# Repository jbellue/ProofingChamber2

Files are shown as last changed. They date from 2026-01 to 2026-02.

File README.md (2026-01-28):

# Proofing Chamber 2

A smart, temperature-controlled proofing chamber project.

## Repository Structure

- firmware/ — ESP32 firmware (PlatformIO)
- hardware/ — KiCad designs and vendor references
  - boards/ — device PCB projects
  - libraries/ — project symbols/footprints
  - docs/ — exports (PDFs, BOMs)
  - third_party/ — external references (git submodules)

## Quick Start

### Firmware

1. Install PlatformIO (VS Code extension or CLI)
2. Build from the firmware folder:

```
cd firmware
pio run
```

### Hardware Vendor References

If the repository was cloned without submodules, fetch them:

```
git submodule update --init --recursive
```

## Detailed Docs

- See firmware details in firmware/README.md
- Hardware-specific docs live under hardware/ (or board project folders)

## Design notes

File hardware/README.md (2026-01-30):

OLED symbol and footprint: https://www.snapeda.com/parts/OLED%20128x64%201.3%22%20I2C/UNIVERSAL-SOLDER%20Electronics%20Ltd/view-part/
OLED 3d model: https://grabcad.com/library/1-3-oled-display-128x64-1

Encoder 3d model: https://www.snapeda.com/parts/PEC11R-4020F-S0024/Bourns/view-part/

ESP32-C3: https://www.snapeda.com/parts/ESP32-C3%20SuperMini_TH/Espressif%20Systems/view-part/

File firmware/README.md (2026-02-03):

# Proofing Chamber

A smart temperature-controlled proofing chamber controller, built with ESP32-C3 and a 128x64 OLED display, with both physical controls and a web interface.

## Interfaces

### Physical Interface
- **Display**: SH1106 128x64 OLED (I2C interface)
- **Input**: Rotary encoder with push-button switch for menu navigation
- **LEDs**: Visual indicators for heating (GPIO 6) and cooling (GPIO 5) modes

### Web Interface
- **Access**: Browser-based control panel accessible on local network
- **Features**: Live temperature monitoring, mode control, settings adjustment
- **Documentation**: See [WEB_INTERFACE.md](WEB_INTERFACE.md)

Both interfaces work concurrently and share the same device state.

## Hardware

### Components

- **Microcontroller**: ESP32-C3-DevKitM-1
- **Display**: SH1106 128x64 OLED (I2C interface)
- **Temperature Sensor**: DS18B20 (1-Wire protocol)
- **Rotary Encoder**: With push-button switch for menu navigation
- **Relays**: 
  - Heating relay (GPIO 2)
  - Cooling relay (GPIO 1)
- **LEDs**:
  - Proofing LED (GPIO 6) - indicates heating mode
  - Cooling LED (GPIO 5) - indicates cooling mode

### Wiring Diagram

```
ESP32-C3
├── GPIO 0  → DS18B20 (1-Wire)
├── GPIO 1  → Cooling Relay
├── GPIO 2  → Heating Relay
├── GPIO 3  → Rotary Encoder CLK
├── GPIO 4  → Rotary Encoder DT
├── GPIO 5  → Cooling LED (cathode to GND)
├── GPIO 6  → Proofing LED (cathode to GND)
├── GPIO 10 → Rotary Encoder SW
├── SDA (GPIO 8)  → SH1106 OLED SDA
├── SCL (GPIO 9)  → SH1106 OLED SCL
└── GND → All grounds connected

Power:
├── 5V → OLED VCC, Relay logic power
├── 3.3V → ESP32 power
└── GND → All grounds
```

## Features

### Temperature Control

- **Heating Mode**: Maintains target temperature using hysteresis control
  - Turns heater ON below lower limit
  - Turns heater OFF above upper limit
- **Cooling Mode**: Maintains target temperature with active cooling
  - Turns cooler ON above upper limit
  - Turns cooler OFF below lower limit

### Menu System

Navigate with rotary encoder, select with push button:

1. **Mettre en pousse** (Start Proofing) - Immediate heating mode
2. **Mettre en froid** (Cooling)
   - Pousser à... (Proof at specific time)
   - Pousser dans... (Proof in X time)
3. **Réglages** (Settings)
   - **Chaud** (Heating Settings)
     - Lower temperature limit
     - Upper temperature limit
   - **Froid** (Cooling Settings)
     - Lower temperature limit
     - Upper temperature limit
   - **Avancés** (Advanced Settings)
     - Données (Display current temperature)
     - Reset du WiFi (Reset WiFi & reboot)
     - Fuseau horaire (Timezone)
     - Redémarrer (Reboot)

### Data Storage

Settings are persisted to ESP32 NVS (Non-Volatile Storage) using the Preferences library:

```
Preference Keys:
  - h_lower
  - h_upper
  - c_lower
  - c_upper
  - timezone
```

Default values:
- **Heating**: Range 28-35°C
- **Cooling**: Range 2-7°C

### Network Features

- WiFi Manager for easy WiFi configuration
- NTP time synchronization (configurable timezone)
- WiFi reset option available in advanced settings
- **Web Interface**: Browser-based control panel on port 80
  - Real-time temperature monitoring
  - Remote mode switching (heating/cooling/off)
  - Temperature settings adjustment
  - Works concurrently with physical interface
  - See [WEB_INTERFACE.md](WEB_INTERFACE.md) for details

## Installation & Setup

### Prerequisites

- PlatformIO IDE or VS Code with PlatformIO extension
- Python 3.6+

### First Boot

1. Device will attempt to connect to WiFi via WiFi Manager
2. If no WiFi found, connect to the ESP32's AP and configure WiFi
3. Device will sync time from NTP server
4. Main menu will appear on display

## Usage Guide

### Starting a Proof

1. From main menu, select **Mettre en pousse**
   - Immediately activates heating mode
   - Displays elapsed time and current temperature
   - Shows temperature graph
   - Press button to cancel and return to menu

### Cooling with Delayed Start

1. From main menu, select **Mettre en froid** → **Pousser dans...**
2. Use encoder to set hours and minutes for delay
3. Press button to confirm each field
4. Device will cool until specified time, then switch to heating
5. Proofing screen appears when time reached

### Scheduled Proof

1. From main menu, select **Mettre en froid** → **Pousser à...**
2. Set the time when proofing should start (current time shown by default)
3. Device will cool until that time, then switch to heating

### Adjusting Temperature Limits

1. Navigate to **Réglages** → **Chaud** or **Froid**
2. Select the limit you want to adjust
3. Use encoder to increase/decrease value
4. Press button to confirm and save

### Temperature Graph

- Displays on proofing and cooling screens
- X-axis: Time (most recent on right)
- Y-axis: Temperature scale (configured per mode)
- Updates every 10 seconds

## Development

### Architecture

The project uses a layered architecture:

```
UI Layer (Views)
    ↓
Controllers (Screen Logic)
    ↓
Services (Temperature, Storage, Network, Reboot)
    ↓
Hardware Drivers (InputManager, DisplayManager, DS18B20Manager)
    ↓
Hardware (ESP32 Peripherals)
```

### Key Classes

- `Menu` - Main menu navigation
- `ProofingController` - Heating mode logic
- `CoolingController` - Cooling mode logic
- `TemperatureController` - Relay control & hysteresis
- `StorageAdapter` - Persistent settings
- `NetworkService` - WiFi & NTP

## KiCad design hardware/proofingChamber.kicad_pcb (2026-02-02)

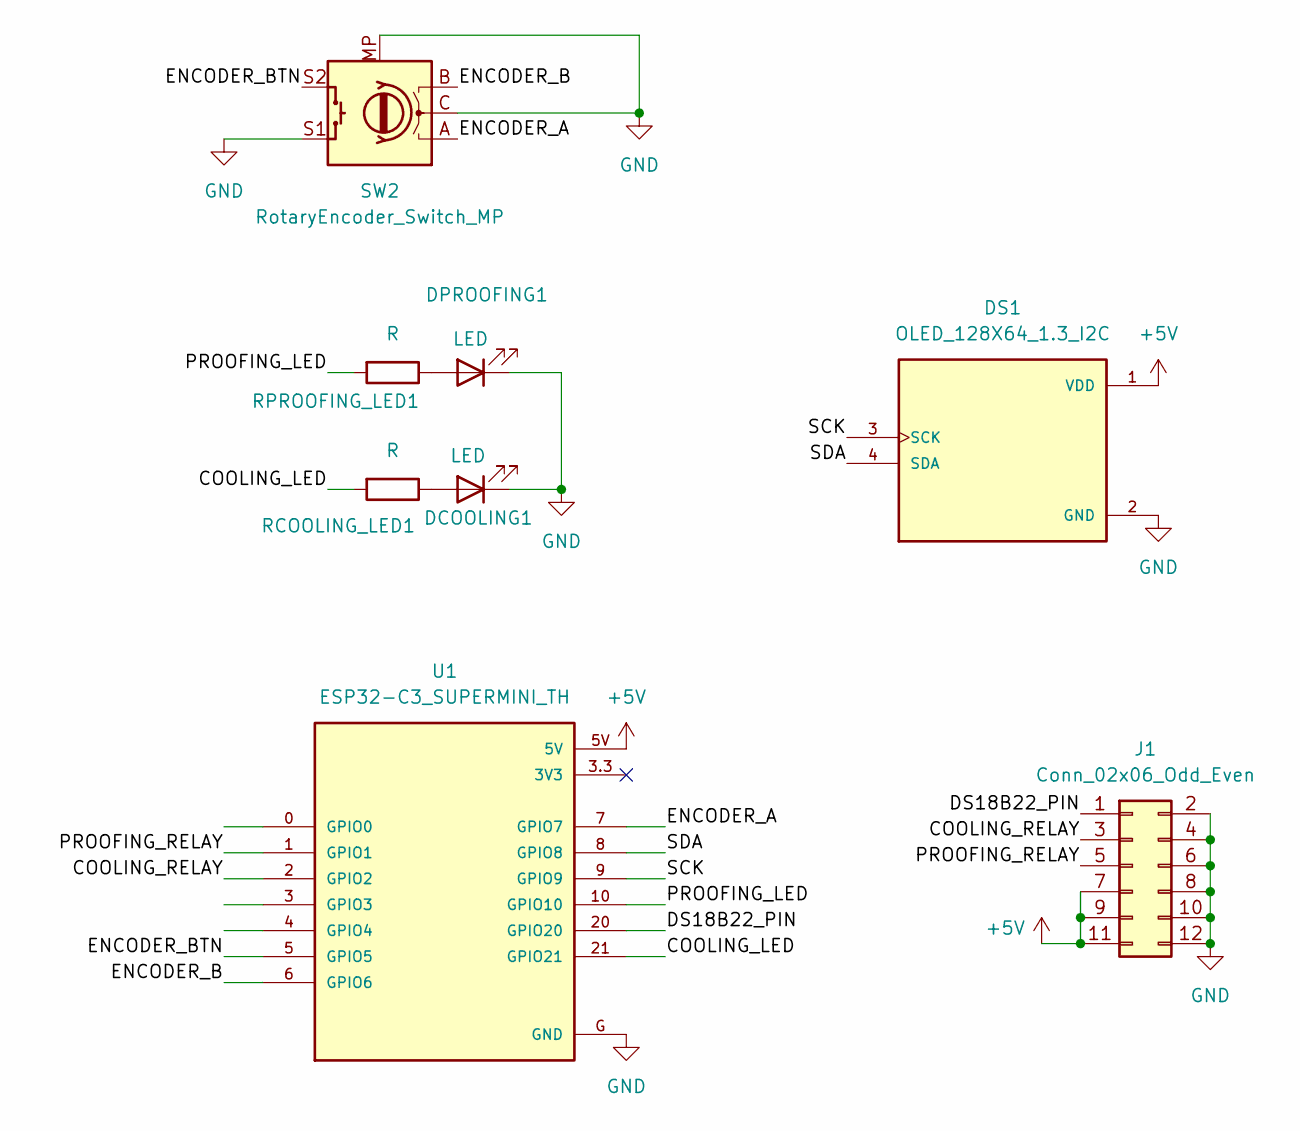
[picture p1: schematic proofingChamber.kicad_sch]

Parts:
DCOOLING1: LED; LED_D3.0mm
DPROOFING1: LED; LED_D3.0mm
DS1: OLED_128X64_1.3_I2C; LCD_OLED_128X64_1.3_I2C; PARTREV NA
J1: Conn_02x06_Odd_Even; PinSocket_2x06_P2.54mm_Horizontal
RCOOLING_LED1: R; R_Axial_DIN0207_L6.3mm_D2.5mm_P7.62mm_Horizontal
RPROOFING_LED1: R; R_Axial_DIN0207_L6.3mm_D2.5mm_P7.62mm_Horizontal
SW2: RotaryEncoder_Switch_MP; RotaryEncoder_Alps_EC11E-Switch_Vertical_H20mm
U1: ESP32-C3_SUPERMINI_TH; MODULE_ESP32-C3_SUPERMINI_TH

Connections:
+5V: DS1.1 (VDD), J1.7, J1.9, J1.11, U1.5V
/COOLING_LED: RCOOLING_LED1.2, U1.21 (GPIO21)
/COOLING_RELAY: J1.3, U1.2 (GPIO2)
/DS18B22_PIN: J1.1, U1.20 (GPIO20)
/ENCODER_A: SW2.A, U1.7 (GPIO7)
/ENCODER_B: SW2.B, U1.6 (GPIO6)
/ENCODER_BTN: SW2.S2, U1.5 (GPIO5)
/PROOFING_LED: RPROOFING_LED1.2, U1.10 (GPIO10)
/PROOFING_RELAY: J1.5, U1.1 (GPIO1)
/SCK: DS1.3 (SCK), U1.9 (GPIO9)
/SDA: DS1.4 (SDA), U1.8 (GPIO8)
GND: DCOOLING1.1 (K), DPROOFING1.1 (K), DS1.2 (GND), J1.2, J1.4, J1.6, J1.8, J1.10, J1.12, SW2.C, SW2.MP, SW2.S1, U1.G (GND)
unnamed: DCOOLING1.2 (A), RCOOLING_LED1.1
unnamed: DPROOFING1.2 (A), RPROOFING_LED1.1

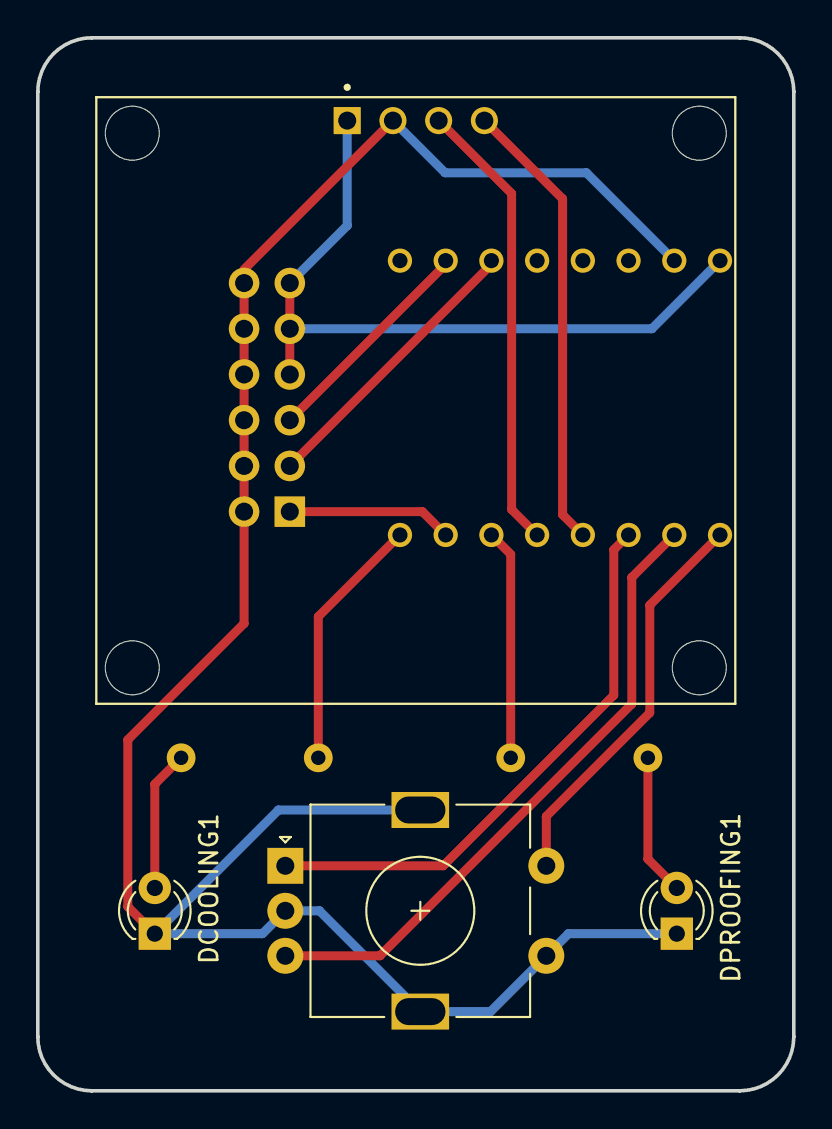
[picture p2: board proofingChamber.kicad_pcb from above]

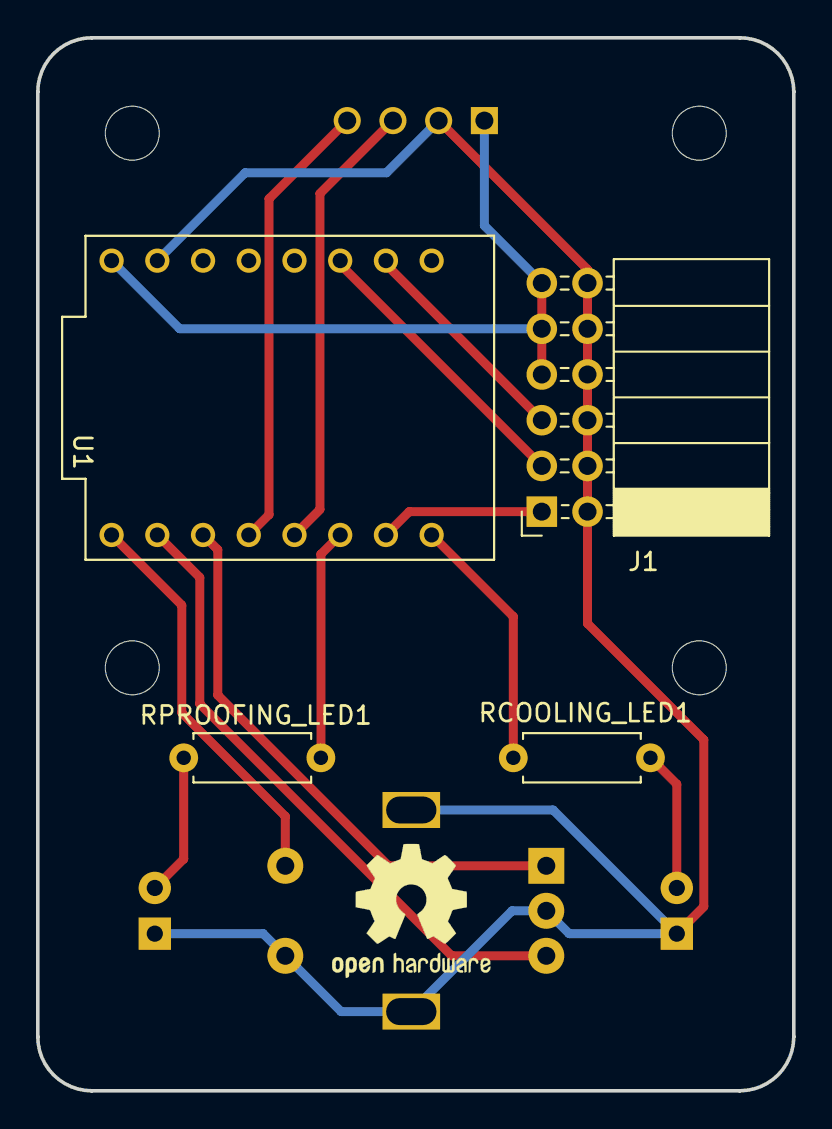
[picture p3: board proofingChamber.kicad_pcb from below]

Board: 2 copper layers, 42.0 x 58.5 mm, 8 parts (4 on the bottom side), 14 nets.

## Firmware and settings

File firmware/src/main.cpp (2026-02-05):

#include <U8g2lib.h>
#include <driver/gpio.h>
#include <esp_log.h>
#include "DebugUtils.h"
#include "DisplayManager.h"
#include "InputManager.h"
#include "MenuActions.h"
#include "MenuItems.h"
#include "screens/Initialization.h"
#include "screens/Menu.h"
#include "services/RebootService.h"
#include "services/NetworkService.h"
#include "services/StorageAdapter.h"
#include "services/IStorage.h"
#include "services/WebServerService.h"
#include "screens/controllers/ProofingController.h"
#include "screens/controllers/AdjustTimeController.h"
#include "screens/controllers/AdjustValueController.h"
#include "screens/controllers/RebootController.h"
#include "screens/controllers/WiFiResetController.h"
#include "screens/controllers/CoolingController.h"
#include "screens/controllers/DataDisplayController.h"
#include "screens/controllers/ConfirmTimezoneController.h"
#include "screens/controllers/PowerOffController.h"
#include "screens/views/AdjustValueView.h"
#include "screens/views/AdjustTimeView.h"
#include "screens/views/CoolingView.h"
#include "screens/views/ProofingView.h"
#include "screens/views/RebootView.h"
#include "screens/views/WiFiResetView.h"
#include "screens/views/DataDisplayView.h"
#include "screens/views/ConfirmTimezoneView.h"
#include "screens/views/PowerOffView.h"
#include "ScreensManager.h"
#include "Storage.h"
#include "TemperatureController.h"
#include "AppContextDecl.h"

#define DS18B20_PIN       GPIO_NUM_20 //update prototype
#define COOLING_RELAY_PIN GPIO_NUM_2  //update prototype
#define HEATING_RELAY_PIN GPIO_NUM_1  //update prototype
#define ENCODER_CLK       GPIO_NUM_6  //update prototype
#define ENCODER_DT        GPIO_NUM_7  //update prototype
#define ENCODER_SW        GPIO_NUM_5
#define PROOFING_LED_PIN  GPIO_NUM_10 //update prototype
#define COOLING_LED_PIN   GPIO_NUM_21 //update prototype

// Global objects
DisplayManager displayManager(U8G2_R0);
// Storage adapter and temperature controller depend on storage
services::StorageAdapter storageAdapter;
TemperatureController temperatureController(HEATING_RELAY_PIN, COOLING_RELAY_PIN, PROOFING_LED_PIN, COOLING_LED_PIN);

ScreensManager screensManager;
InputManager inputManager(ENCODER_CLK, ENCODER_DT, ENCODER_SW, DS18B20_PIN);
// Global AppContext instance (defined early so globals can receive its pointer)
AppContext appContext;

// Static controller instances (stack allocated)
static AdjustValueController adjustValueControllerInstance(&appContext);
static AdjustTimeController adjustTimeControllerInstance(&appContext);
static ProofingController proofingControllerInstance(&appContext);
static RebootController rebootInstance(&appContext);
static CoolingController coolingControllerInstance(&appContext);
static WiFiResetController wifiResetControllerInstance(&appContext);
static DataDisplayController dataDisplayControllerInstance(&appContext);
static ConfirmTimezoneController confirmTimezoneControllerInstance(&appContext);
static PowerOffController powerOffControllerInstance(&appContext);

AdjustValueController* adjustValueController = &adjustValueControllerInstance;
AdjustTimeController* adjustTimeController = &adjustTimeControllerInstance;
ProofingController* proofingController = &proofingControllerInstance;
RebootController* reboot = &rebootInstance;
CoolingController* coolingController = &coolingControllerInstance;
WiFiResetController* wifiResetController = &wifiResetControllerInstance;
DataDisplayController* dataDisplayController = &dataDisplayControllerInstance;
ConfirmTimezoneController* confirmTimezoneController = &confirmTimezoneControllerInstance;
PowerOffController* powerOffController = &powerOffControllerInstance;
Initialization* initialization = nullptr; // Created in setup after network service

MenuActions* menuActions = nullptr; // Created in setup
Menu* menu = nullptr; // Created in setup

// Network and reboot services
services::NetworkService networkService;
services::RebootService rebootService;
services::WebServerService webServerService(&appContext);

// Static view instances (allocated on stack)
static AdjustValueView adjustValueView(&displayManager);
static AdjustTimeView adjustTimeView(&displayManager);
static CoolingView coolingView(&displayManager);
static ProofingView proofingView(&displayManager);
static RebootView rebootView(&displayManager);
static WiFiResetView wifiResetView(&displayManager);
static DataDisplayView dataDisplayView(&displayManager);
static ConfirmTimezoneView confirmTimezoneView(&displayManager);
static PowerOffView powerOffView(&displayManager);

void setup() {
#if defined CORE_DEBUG_LEVEL && CORE_DEBUG_LEVEL > ARDUHAL_LOG_LEVEL_NONE
    // Initialize serial communication
    Serial.begin(115200);
#endif
    // Release any deep-sleep GPIO holds from previous power-off
    gpio_deep_sleep_hold_dis();
    gpio_hold_dis(COOLING_LED_PIN);
    gpio_hold_dis(PROOFING_LED_PIN);
    gpio_hold_dis(HEATING_RELAY_PIN);
    gpio_hold_dis(COOLING_RELAY_PIN);
    if (!storageAdapter.begin()) {
        DEBUG_PRINTLN("Storage initialization failed - using safe defaults");
        // Set safe default temperatures (moderate room temperature range)
        temperatureController.setDefaultLimits(23, 27);
    }
    displayManager.begin();
    inputManager.begin();
    temperatureController.begin();

    // Initialize output pin
    gpio_reset_pin(COOLING_LED_PIN);
    gpio_set_direction(COOLING_LED_PIN, GPIO_MODE_OUTPUT);
    gpio_reset_pin(PROOFING_LED_PIN);
    gpio_set_direction(PROOFING_LED_PIN, GPIO_MODE_OUTPUT);
    gpio_reset_pin(HEATING_RELAY_PIN);
    gpio_set_direction(HEATING_RELAY_PIN, GPIO_MODE_OUTPUT);
    gpio_reset_pin(COOLING_RELAY_PIN);
    gpio_set_direction(COOLING_RELAY_PIN, GPIO_MODE_OUTPUT);

    // Populate global AppContext so components can access shared services
    appContext.display = &displayManager;
    appContext.input = &inputManager;
    appContext.screens = &screensManager;
    appContext.tempController = &temperatureController;
    appContext.rebootService = &rebootService;
    appContext.networkService = &networkService;
    appContext.storage = &storageAdapter;
    appContext.webServerService = &webServerService;
    appContext.encoderButtonPin = ENCODER_SW;
    appContext.heaterRelayPin = HEATING_RELAY_PIN;
    appContext.coolerRelayPin = COOLING_RELAY_PIN;
    appContext.proofingLedPin = PROOFING_LED_PIN;
    appContext.coolingLedPin = COOLING_LED_PIN;
    
    // Add view pointers to AppContext
    appContext.adjustValueView = &adjustValueView;
    appContext.adjustTimeView = &adjustTimeView;
    appContext.coolingView = &coolingView;
    appContext.proofingView = &proofingView;
    appContext.rebootView = &rebootView;
    appContext.wifiResetView = &wifiResetView;
    appContext.dataDisplayView = &dataDisplayView;
    appContext.confirmTimezoneView = &confirmTimezoneView;
    appContext.powerOffView = &powerOffView;
    
    // Add controller pointers to AppContext
    appContext.proofingController = proofingController;
    appContext.coolingController = coolingController;

    // Provide storage to TemperatureController now that AppContext.storage is set
    temperatureController.setStorage(appContext.storage);

    // Create remaining objects that depend on appContext being fully initialized
    static Initialization initializationInstance(&appContext);
    initialization = &initializationInstance;
    
    static MenuActions menuActionsInstance(&appContext, adjustValueController, adjustTimeController, proofingController, coolingController, wifiResetController, reboot, dataDisplayController, confirmTimezoneController, powerOffController);
    menuActions = &menuActionsInstance;
    
    static Menu menuInstance(&appContext, menuActions);
    menu = &menuInstance;
    
    // Add menu and menuActions to AppContext for web access
    appContext.menuActions = menuActions;
    appContext.menu = menu;
    
    // Initialize dynamic timezone menus
    initializeAllMenus(&appContext);
    
    // Set the menu instance in MenuActions for context-aware actions
    menuActions->setMenu(&menuInstance);

    initialization->setNextScreen(menu);
    screensManager.setActiveScreen(initialization);
}

void loop() {
    static unsigned long lastWebUpdate = 0;
    unsigned long now = millis();
    
    inputManager.update();
    screensManager.update();
    
    // Broadcast state to web every 500ms (ensures web stays in sync with device)
    if (appContext.webServerService && now - lastWebUpdate >= 500) {
        appContext.webServerService->broadcastScreenState();
        lastWebUpdate = now;
    }
}

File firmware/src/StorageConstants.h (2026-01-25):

#pragma once

namespace storage
{
    namespace keys
    {
        static constexpr char HOT_LOWER_LIMIT_KEY[] = "h_lower";
        static constexpr char HOT_UPPER_LIMIT_KEY[] = "h_upper";
        static constexpr char COLD_LOWER_LIMIT_KEY[] = "c_lower";
        static constexpr char COLD_UPPER_LIMIT_KEY[] = "c_upper";
        static constexpr char TIMEZONE_KEY[] = "timezone";
    }
    namespace defaults
    {
        static constexpr int HOT_LOWER_LIMIT_DEFAULT = 23;
        static constexpr int HOT_UPPER_LIMIT_DEFAULT = 32;
        static constexpr int COLD_LOWER_LIMIT_DEFAULT = 2;
        static constexpr int COLD_UPPER_LIMIT_DEFAULT = 7;
        static constexpr char TIMEZONE_DEFAULT[] = "CET-1CEST,M3.5.0,M10.5.0/3";
    }
}

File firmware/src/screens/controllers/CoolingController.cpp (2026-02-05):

#include "CoolingController.h"
#include "DebugUtils.h"
#include "../views/CoolingView.h"
#include "../../ScreensManager.h"
#include "../Menu.h"
#include "../../services/IWebServerService.h"
#include "ProofingController.h"

CoolingController::CoolingController(AppContext* ctx)
    : BaseController(ctx), _view(nullptr), _temperatureController(nullptr),
    _proofingController(nullptr), _menuScreen(nullptr) {}

void CoolingController::beginImpl() {
    initializeInputManager();
    
    AppContext* ctx = getContext();
    if (ctx) {
        if (!_temperatureController) _temperatureController = ctx->tempController;
        if (!_view) _view = ctx->coolingView;
    }
    
    getInputManager()->slowTemperaturePolling(false);
    // Only use timeCalculator if _endTime is not already set (from web API)
    if (_endTime == 0) {
        _endTime = _timeCalculator ? _timeCalculator() : 0;
    }
    _lastUpdateTime = 0;
    _lastGraphUpdate = 0;
    _onCancelButton = true;
    _temperatureController->setMode(ITemperatureController::COOLING);
    _temperatureGraph.configure(30, 15, -5.0, 60.0, true);
    _view->start(_endTime, _onCancelButton, _temperatureGraph);
}

bool CoolingController::update(bool shouldRedraw) {
    IInputManager* inputManager = getInputManager();
    struct tm tm_now;
    getLocalTime(&tm_now);
    const time_t now = mktime(&tm_now);

    // Don't recalculate _endTime on force redraw - it's already set in beginImpl()
    // Force redraw should just refresh display, not change state
    bool timesUp = now >= _endTime;
    if (inputManager->isButtonPressed() || timesUp) {
        inputManager->slowTemperaturePolling(true);
        _temperatureController->setMode(ITemperatureController::OFF);
        _endTime = 0; // Reset when exiting
        bool goingToProofScreen = !_onCancelButton || timesUp;
        
        // Notify web that cooling has stopped
        AppContext* ctx = getContext();
        if (ctx->webServerService) {
            ctx->webServerService->notifyStateChange();
        }
        
        if (goingToProofScreen && _proofingController) {
            // When transitioning to proofing (timer expired), actually start proofing
            // Cast to ProofingController to access startProofing()
            ProofingController* proofController = static_cast<ProofingController*>(_proofingController);
            if (proofController) {
                proofController->startProofing();
            }
        } else {
            // When cancelling to menu, just navigate
            BaseController* nextScreen = _menuScreen;
            setNextScreen(nextScreen);
            if (nextScreen) nextScreen->begin();
        }
        return false;
    }
    // Force update on first draw or when enough time has passed
    if (shouldRedraw || difftime(now, _lastUpdateTime) >= 1) {
        const float currentTemp = inputManager->getTemperature();
        _temperatureGraph.addValueToAverage(currentTemp);
        shouldRedraw |= _view->drawTemperature(currentTemp);
        _temperatureController->update(currentTemp);
        shouldRedraw |= _view->drawTime(difftime(_endTime, now));
        _lastUpdateTime = now;
        if (shouldRedraw || difftime(now, _lastGraphUpdate) >= 10.0) {
            _temperatureGraph.commitAverage(currentTemp);
            _lastGraphUpdate = now;
            _view->drawGraph(_temperatureGraph);
            shouldRedraw = true;
        }
    }

    shouldRedraw |= _view->drawIcons(OptionalBool(_temperatureController->isCooling()));

    auto encoderDirection = inputManager->getEncoderDirection();
    if (encoderDirection != IInputManager::EncoderDirection::None) {
        _onCancelButton = !_onCancelButton;
        _view->drawButtons(_onCancelButton);
        shouldRedraw = true;
    }

    if (shouldRedraw) {
        _view->sendBuffer();
    }
    return true;
}


void CoolingController::prepare(TimeCalculatorCallback callback, BaseController* proofingController, BaseController* menuScreen) {
    _timeCalculator = callback;
    _proofingController = proofingController;
    _menuScreen = menuScreen;
}

void CoolingController::startCooling(time_t endTime) {
    AppContext* ctx = getContext();
    if (!ctx || !ctx->tempController) return;
    
    _temperatureController = ctx->tempController;
    _endTime = endTime;
    _lastUpdateTime = 0;
    _lastGraphUpdate = 0;
    
    _temperatureController->setMode(ITemperatureController::COOLING);
    _temperatureGraph.configure(30, 15, -5.0, 60.0, true);
    
    DEBUG_PRINTLN("[CoolingController] Started cooling from web API");
    
    // Navigate display to show cooling screen
    if (ctx->screens) {
        ctx->screens->setActiveScreen(this);
        begin(); // Initialize the screen - calls beginImpl() which calls _view->start()
        // Small delay to ensure view is fully initialized
        delay(10);
        // Update dynamic content (temperature, time, icons) and send to display
        // Note: beginImpl() already drew the static parts (title, buttons, graph)
        if (ctx->display) {
            update(true); // Force update of dynamic content
            ctx->display->sendBuffer();
        }
    }
    
    // Notify web view of state change (web is a VIEW)
    if (ctx->webServerService) {
        ctx->webServerService->notifyStateChange();
    }
}

void CoolingController::startCoolingWithDelay(int hours) {
    struct tm now;
    getLocalTime(&now);
    time_t currentTime = mktime(&now);
    time_t endTime = currentTime + (hours * 3600);
    startCooling(endTime);
}

void CoolingController::stopCooling() {
    AppContext* ctx = getContext();
    if (_temperatureController) {
        _temperatureController->setMode(ITemperatureController::OFF);
    }
    _endTime = 0;
    
    DEBUG_PRINTLN("[CoolingController] Stopped cooling from web API");
    
    // Navigate back to menu
    if (ctx && ctx->screens && ctx->menu) {
        ctx->screens->setActiveScreen(ctx->menu);
        ctx->menu->begin(); // Initialize menu to prevent blank screen
        // Force display refresh
        if (ctx->display) {
            ctx->display->clearBuffer();
            ctx->menu->update(true); // Force redraw
            ctx->display->sendBuffer();
        }
    }
    
    // Notify web view of state change (web is a VIEW)
    if (ctx->webServerService) {
        ctx->webServerService->notifyStateChange();
    }
}

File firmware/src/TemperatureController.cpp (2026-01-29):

#include "TemperatureController.h"
#include "DebugUtils.h"
#include "services/IStorage.h"
#include "StorageConstants.h"

TemperatureController::TemperatureController(const gpio_num_t heaterPin, const gpio_num_t coolerPin, const gpio_num_t proofingLedPin, const gpio_num_t coolingLedPin)
    : _heaterPin(heaterPin)
    , _coolerPin(coolerPin)
    , _proofingLedPin(proofingLedPin)
    , _coolingLedPin(coolingLedPin)
    , _currentMode(OFF)
    , _storage(nullptr)
    , _lowerLimit(0)
    , _higherLimit(0)
    , _isHeating(false)
    , _isCooling(false)
{
}

void TemperatureController::setStorage(services::IStorage* storage) {
    _storage = storage;
}

void TemperatureController::setDefaultLimits(int8_t lower, int8_t higher) {
    _lowerLimit = lower;
    _higherLimit = higher;
    DEBUG_PRINTLN("Using default temperature limits");
    DEBUG_PRINT("Lower: "); DEBUG_PRINTLN(_lowerLimit);
    DEBUG_PRINT("Higher: "); DEBUG_PRINTLN(_higherLimit);
}

void TemperatureController::begin() {
    turnHeater(false);
    turnCooler(false);
}

void TemperatureController::setMode(Mode mode) {
    if (_currentMode == mode) return;
    
    _currentMode = mode;
    loadTemperatureSettings();

    // Safety: turn off both relays when changing modes
    turnHeater(false);
    turnCooler(false);

    // Control LEDs based on mode
    switch (_currentMode) {
        case HEATING:
            gpio_set_level(_proofingLedPin, 1);
            gpio_set_level(_coolingLedPin, 0);
            break;
        case COOLING:
            gpio_set_level(_proofingLedPin, 0);
            gpio_set_level(_coolingLedPin, 1);
            break;
        case OFF:
            gpio_set_level(_proofingLedPin, 0);
            gpio_set_level(_coolingLedPin, 0);
            break;
    }
}

void TemperatureController::loadTemperatureSettings() {
    switch (_currentMode)
    {
        case HEATING:

            _lowerLimit = _storage->getInt(storage::keys::HOT_LOWER_LIMIT_KEY, storage::defaults::HOT_LOWER_LIMIT_DEFAULT);
            _higherLimit = _storage->getInt(storage::keys::HOT_UPPER_LIMIT_KEY, storage::defaults::HOT_UPPER_LIMIT_DEFAULT);
            break;
        case COOLING:
            _lowerLimit = _storage->getInt(storage::keys::COLD_LOWER_LIMIT_KEY, storage::defaults::COLD_LOWER_LIMIT_DEFAULT);
            _higherLimit = _storage->getInt(storage::keys::COLD_UPPER_LIMIT_KEY, storage::defaults::COLD_UPPER_LIMIT_DEFAULT);
            break;
        case OFF:
            return; // No need to load settings when off
    }

    DEBUG_PRINT("Mode: ");
    DEBUG_PRINTLN(_currentMode == HEATING ? "HEATING" : "COOLING");
    DEBUG_PRINT("Lower: ");
    DEBUG_PRINTLN(_lowerLimit);
    DEBUG_PRINT("Higher: ");
    DEBUG_PRINTLN(_higherLimit);
}

void TemperatureController::update(float currentTemp) {
    if (_currentMode == OFF) {
        turnHeater(false);
        turnCooler(false);
        return;
    }

    updateRelays(currentTemp);
}

/**
 * @brief Updates the heating/cooling relays based on current temperature and mode.
 * 
 * This method implements hysteresis control using lower and higher temperature limits.
 * The hysteresis prevents rapid relay switching by creating a temperature range:
 * - In HEATING mode: heater turns ON below lower limit, OFF above higher limit
 * - In COOLING mode: cooler turns ON above higher limit, OFF below lower limit
 * 
 * The gap between lower and higher limits provides the hysteresis band that
 * maintains temperature stability and protects relay lifespan.
 * 
 * @param currentTemp The current temperature reading to compare against limits
 */
void TemperatureController::updateRelays(float currentTemp) {
    switch (_currentMode) {
        case HEATING:
            if (currentTemp < _lowerLimit) {
                DEBUG_PRINTLN("Turning the heater ON");
                turnHeater(true);
                turnCooler(false);
            } else if (currentTemp > _higherLimit) {
                DEBUG_PRINTLN("Turning the heater OFF");
                turnHeater(false);
                turnCooler(false);
            }
            break;
        case COOLING:
            if (currentTemp > _higherLimit) {
                DEBUG_PRINTLN("Turning the cooler ON");
                turnCooler(true);
                turnHeater(false);
            } else if (currentTemp < _lowerLimit) {
                DEBUG_PRINTLN("Turning the cooler OFF");
                turnCooler(false);
                turnHeater(false);
            }
            break;
        case OFF: // No action needed
            break;
    }
}

TemperatureController::Mode TemperatureController::getMode() const {
    return _currentMode;
}

bool TemperatureController::isHeating() const {
    return _isHeating;
}

bool TemperatureController::isCooling() const {
    return _isCooling;
}

void TemperatureController::turnHeater(bool on) {
    gpio_set_level(_heaterPin, on ? 1 : 0);
    _isHeating = on;
}

void TemperatureController::turnCooler(bool on) {
    gpio_set_level(_coolerPin, on ? 1 : 0);
    _isCooling = on;
}

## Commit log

2025-02-24 Adjust encoder count handling for smoother menu navigation
2025-03-13 Refactor Menu class to use RotaryEncoder and update encoder handling for improved functionality
2025-03-14 Fix UTF-8 encoding for menu item names and update display font for better compatibility
    [Menu.cpp]
2025-03-14 Initialize _oldPosition to 0 for correct menu navigation behavior
    [Menu.cpp]
2025-03-15 Refactor Menu::adjustValue for improved encoder handling and add updateAdjustValueDisplay for better display logic
2025-03-16 Add more settings menu and WiFi reset functionality; refactor display handling
    [Menu.cpp, Menu.h, main.cpp]
2025-03-18 Add InputManager class for encoder handling and refactor Menu to utilize InputManager
2025-03-18 Refactor time adjustment logic to handle day rollover and update display to show current days
2025-03-23 Add WiFiReset screen and integrate with MenuActions for Wi-Fi reset functionality
    [main.cpp]
2025-03-23 Add setCursor and print methods to DisplayManager for improved text handling
2025-03-24 Remove debug print statement from AdjustValue update method
2025-03-25 Refactor ProofingScreen to simplify begin method and improve temperature handling
2025-03-25 Refactor CoolingScreen to improve button layout and display remaining time in a more user-friendly format
2025-03-25 Refactor SetTimezone and WiFiReset screens to use constants for button text for improved readability
2025-03-28 Refactor InputManager and related screens to use encoder direction for adjustments, improving clarity and consistency
2025-03-28 Update encoder switch pin definition for consistency
2025-03-29 Add DS18B20 temperature sensor support and refactor InputManager for temperature polling
2025-03-30 Add Graph class for temperature data visualization and integrate into ProofingScreen
2025-03-30 Update ProofingScreen to commit temperature average with current temperature
2025-03-30 Initialize previous temperature to a high value for proper first update rendering
2025-03-31 Enhance InputManager to handle button press state and improve debounce logic
2025-03-31 Add lastTemperatureUpdate to optimize temperature polling and redraw logic
2025-03-31 Refactor DS18B20Manager to improve temperature reading logic and error recovery
2025-03-31 Refactor AdjustValue to improve display logic and add button functionality
2025-04-01 Refactor button drawing logic in DisplayManager and screens to utilize new drawButton and drawButtons methods
2025-04-04 WIP - Add TemperatureController class for managing heating and cooling logic
2025-04-04 Add resetEncoderPosition method and update input manager initialization in screens
    [InputManager.cpp, Menu.cpp]
2025-04-04 Add initialization check in InputManager to prevent re-initialization
    [InputManager.cpp]
2025-04-04 Refactor TemperatureController integration in screens and improve mode handling
2025-04-04 Fix pin assignments for temperature and encoder components in main.cpp
    [main.cpp]
2025-04-04 Add reboot functionality to MenuActions and implement Reboot screen
    [main.cpp]
2026-01-02 Add note about I2C pins for OLED display
2026-01-19 Test (#7)
    * WIP - massive refactor for better separation of concerns
    * More refactor
    * Refactor MenuActions and MenuItems to improve null checks and use lambda functions for action binding
    * Refactor WiFiReset functionality into WiFiResetController and WiFiResetView for improved structure and separation of concerns
    * Refactor MenuActions to use SetTimezoneController and SetTimezoneView for improved structure and separation of concerns; remove SetTimezone implementation
    * Refactor MenuActions to use AdjustTimeController and AdjustTimeView; remove AdjustTime implementation for improved structure and separation of concerns
    * Refactor view classes to inherit from IBaseView for improved str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
    [AdjustTimeController.cpp, AdjustValueController.cpp]
2026-01-24 Add smooth scrolling to menu navigation with fixed selection highlight (#8)
    * Initial plan
    * Implement smooth menu scrolling with smart positioning
    * Address code review feedback - add cmath include and remove unused variable
    * Replace C-style casts with static_cast for type safety
    * Add algorithm header for min/max functions
    * Use std:: prefix for portability and define magic numbers as constants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
    [Menu.cpp, Menu.h]
2026-01-24 Fix menu encoder input to never skip steps (#9)
    * Fix menu double-scroll by always consuming encoder input
    * Always process encoder input, let animation catch up to new target
    * Drain all pending encoder steps in single update cycle
    * Add safety limit to encoder step processing loop
    * Add getPendingSteps() method for cleaner encoder queue handling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
    [InputManager.cpp, Menu.cpp, Menu.h]
2026-01-25 Add power-off menu item with deep sleep and button wake (#10)
    * Add power-off menu item with confirmation screen and deep sleep
    * Add clarifying comment for hardcoded GPIO pin in power-off
    * Fix: Use esp_deep_sleep_enable_gpio_wakeup for ESP32-C3 and remove dynamic_cast
    * Fix: Use light sleep instead of deep sleep for GPIO10 wakeup on ESP32-C3
    * Add error handling for GPIO wakeup and fix comment
    Co-autho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
    [PowerOffController.cpp, main.cpp]
2026-01-25 Copilot/add poweroff menu item (#12)
    * Add error handling for GPIO wakeup and fix comment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
    [PowerOffController.cpp]
2026-01-25 Replace LittleFS with ESP32 Preferences for persistent storage (#11)
    * Replace LittleFS with Preferences for ESP32 storage
    * Update documentation to reflect Preferences instead of LittleFS
    * Refactor: Remove unnecessary writeToFile helper method
    * Fix: Correct dotIndex check and readStringFromFile return logic
    * Refactor storage handling: replace file paths with preference keys and update storage methods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
    [AdjustValueController.cpp, ConfirmTimezoneController.cpp]
2026-01-27 move firmware to correct folder
    [AdjustTimeController.cpp, AdjustValueController.cpp]
2026-01-28 Add ESP32-C3_SUPERMINI_TH footprint and import guide
    - Created a new KiCad footprint for the ESP32-C3_SUPERMINI_TH module, defining pads and graphical elements for fabrication and silkscreen layers.
    - Added an HTML file for redirecting users to the SnapEDA import guide for the new module.
    [proofingChamber.kicad_pcb, proofingChamber.kicad_sch]
2026-01-29 Refactor GPIO pin handling: replace uint8_t with gpio_num_t for better type safety and add gpioOff function for deep sleep management
    [InputManager.cpp, PowerOffController.cpp, TemperatureController.cpp]
2026-01-29 Refactor LED and relay control: replace digitalWrite with gpio_set_level for improved GPIO handling
    [TemperatureController.cpp]
2026-01-29 Refactor GPIO handling: replace pinMode with gpio_set_direction and update digital states for consistency
    [InputManager.cpp, PowerOffController.cpp, TemperatureController.cpp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]
2026-01-29 Refactor time handling: replace millis() with esp_timer_get_time() for improved accuracy and consistency; add NullRebootService for better service management; update delay calls to use FreeRTOS vTask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
2026-01-29 Refactor logging mechanism: replace conditional debug prints with ESP-IDF logging wrappers for improved logging consistency; update setup function to ensure logging is visible at INFO level.
    [main.cpp]
2026-01-30 Refactor code structure for improved readability and maintainability
    [proofingChamber.kicad_pcb, proofingChamber.kicad_sch]
2026-01-30 Refactor hardware design files: remove obsolete proofingChamber.kicad_prl, update net classes and schematic connections
    [proofingChamber.kicad_pcb, proofingChamber.kicad_sch]
2026-02-02 Update PCB
    [proofingChamber.kicad_pcb, proofingChamber.kicad_sch]
2026-02-03 slight tweak to the schematics
    [proofingChamber.kicad_sch]
2026-02-03 Add temperature validation and improve web UI documentation
2026-02-03 Update web UI to use virtual controls and display current screen
2026-02-03 Fix captive portal - pin WiFiManager to known-working version and add diagnostics
2026-02-03 Fix WiFiManager version - pin EXACTLY to 2.0.16-rc.2 to prevent 2.0.17 upgrade
2026-02-03 Switch to ESP32-specific async WiFiManager library that exists and works
2026-02-03 Add comprehensive documentation for ESP32 async WiFiManager library switch
2026-02-03 Add aggressive AP initialization delays for ESP32-C3 captive portal visibility
2026-02-03 ESP32-C3 timing fix complete - aggressive delays for AP visibility
2026-02-03 Add web interface with virtual controls and fix WiFi captive portal for ESP32-C3
2026-02-04 Remove legacy buttons and add screen content display to web interface
2026-02-04 Add direct action buttons to web interface and remove auto-scroll
2026-02-04 Fix compilation error: include ScreensManager.h in controller implementations
    [CoolingController.cpp]
2026-02-04 Fix type conversion error: include Menu.h to enable BaseController conversion
    [CoolingController.cpp]
2026-02-04 Fix proofing display, remove cooling button, add bread emoji favicon
2026-02-05 Remove unused canvas and fix display refresh after web actions
    [CoolingController.cpp]
2026-02-05 Fix compilation: use webServerService instead of webServer
    [CoolingController.cpp]
2026-02-05 Fix incomplete type error: include IWebServerService.h in controllers
    [CoolingController.cpp]
2026-02-05 Fix web/display sync: add periodic web updates and display refresh delays
    [CoolingController.cpp, main.cpp]
2026-02-05 Fix scheduled proof showing mode OFF: preserve endTime in beginImpl
    [CoolingController.cpp]
2026-02-05 Fix display being mostly empty when triggered from web
    [CoolingController.cpp]
2026-02-05 Fix broken screen when cancelling proofing from device
2026-02-05 Fix cooling screen transition issue from device
    [CoolingController.cpp]
2026-02-05 Fix cooling cancellation, auto-start proofing on timer expiry, reduce redundant WebSocket updates
    [CoolingController.cpp]
2026-02-05 Fix compilation errors: add ITemperatureController include and ProofingController cast
    [CoolingController.cpp]
2026-02-05 Send current state to WebSocket clients immediately on connect
2026-02-05 Refactor WebSocket event handling to improve request validation and update current screen retrieval
